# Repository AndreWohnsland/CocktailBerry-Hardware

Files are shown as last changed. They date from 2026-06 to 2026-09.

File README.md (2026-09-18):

CocktailBerry Hardware

<br/>



CocktailBerry Hardware is the **official hardware repository** for the [CocktailBerry](https://github.com/AndreWohnsland/CocktailBerry) project.
It holds the machine designs (FreeCAD sources) and custom PCB(A)s (KiCad projects) you need to build your own CocktailBerry machine.

<a href="https://cocktailberry.org/">website</a>
<a href="https://hardware.cocktailberry.org/">hardware documentation</a>
<a href="https://docs.cocktailberry.org/">software documentation</a>

Build guides, parts lists, specifications, and downloadable fabrication files live in the
**[Hardware Documentation](https://hardware.cocktailberry.org/)**. For the software, setup, and
configuration, see the [main CocktailBerry project](https://github.com/AndreWohnsland/CocktailBerry)
and the [Software Documentation](https://software.cocktailberry.org/).

Like this project? Give the main repo a star on GitHub! ⭐

# Designs

Sources live in this repo; fabrication files (Gerbers/BOM/CPL for boards, STEP/STL for machines)
are generated from them by the build pipeline. Full specs, parts, and downloads are on the
[Hardware Documentation](https://hardware.cocktailberry.org/).

**PCBAs** ([`pcb/`](pcb)) — control boards that replace relay arrays, switching pump circuits via MOSFETs:

| Board | Description | Status |
| --- | --- | --- |
| [CocktailBerryBoard GPIO](https://hardware.cocktailberry.org/pcbas/cocktailberry-board-gpio/) | GPIO-based, up to 10 circuits | Released |
| [CocktailBerryBoard Slim](https://hardware.cocktailberry.org/pcbas/cocktailberry-board-slim/) | Compact GPIO-based, up to 8 circuits | Released |
| [CocktailBerryBoard I2C](https://hardware.cocktailberry.org/pcbas/cocktailberry-board-i2c/) | I2C-based, up to 10 circuits | Beta |

**Machines** ([`cad/`](cad)) — 3D-printable machine builds:

| Machine | Description | Status |
| --- | --- | --- |
| [CocktailBerry MK III](https://hardware.cocktailberry.org/machines/mk3/) | Compact footprint with integrated touchscreen support  | Released |
| [CocktailBerry 2-Go](https://hardware.cocktailberry.org/machines/2-go/)  | Portable Euro Box build with detachable legs | Released |
| [CocktailBerry MK IV](https://hardware.cocktailberry.org/machines/mk4/)  | v2 reference build, optional scale + peristaltic pumps | Beta |

# Contributing / How to Help

Contributions are very welcome - a new machine design, an improved model, or a PCB layout.
Open an issue or pull request.

**Please submit source files only:**

- PCBs: the KiCad project (`*.kicad_sch`, `*.kicad_pcb`, and any local symbols/footprints)
- Machines: the FreeCAD sources (`*.FCStd`)

Do **not** commit generated fabrication artifacts (Gerbers, drill, CPL, STL, STEP) - those are
built from the sources by the pipeline (see [`pcb/README.md`](pcb/README.md) and
[`cad/README.md`](cad/README.md)). See the main project's
[Contributing Guidelines](https://github.com/AndreWohnsland/CocktailBerry/blob/master/CONTRIBUTING.md)
for general rules.

# Related Projects

| Project | Description |
| --- | --- |
| [CocktailBerry](https://github.com/AndreWohnsland/CocktailBerry) | The main software project (Python + React) |
| [CocktailBerry Addons](https://github.com/AndreWohnsland/CocktailBerry-Addons) | Community addons and extensions |
| [Software Documentation](https://software.cocktailberry.org/) | Software setup and configuration guides |

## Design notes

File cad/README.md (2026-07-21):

# CAD sources

FreeCAD sources for the machines. Manufacturing artifacts (STEP + STL) are
generated headlessly - on release by CI, or locally - via
[`scripts/export_freecad.py`](../scripts/export_freecad.py) (runs under FreeCAD's
`freecadcmd`) and [`scripts/build_artifacts.py`](../scripts/build_artifacts.py)
(the uv-driven orchestrator that zips per machine).

## Layout & conventions

```shell
cad/machines/<machine>/
  *.FCStd        # exported  (files in the folder ROOT)
  lib/           # helpers / imported sources - NOT exported (any subfolder)
  export.toml    # optional: pin which objects to export per file
cad/accessories/ # shared extra hardware - same conventions, own export unit
```

- **File selection:** every `*.FCStd` in a machine-folder **root** is exported.
  Put helper or imported documents in a **subfolder** (e.g. `lib/`) to skip them.
- **Prebuilt files:** `*.3mf` in a folder root are copied into the zip as-is
  (no CAD source needed; pattern list in `build_artifacts.py`).
- **Object selection** per file:
  - One result body in the file → exported automatically, no config needed.
  - Multiple candidates (e.g. a base that forks into variants) → the run fails
    and lists them, so you pin the ones you want in `export.toml`, keyed by the
    file name without `.FCStd`:
    ```toml
    [main_body]
    objects = ["MainBodyStandard", "MainBodyTall", "MainBodyCompact"]
    ```
  - Output files are named after each object's **Label** - name objects
    meaningfully.

## Running

FreeCAD is **not** a uv dependency; install it separately (`apt-get install
freecad` on CI). Then:

```bash
uv run python scripts/build_artifacts.py                # all units -> dist/<unit>.zip
uv run python scripts/build_artifacts.py mk3 accessories # selected units
```

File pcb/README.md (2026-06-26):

# PCB

KiCad projects for the CocktailBerry boards (and room for other PCB-related
components later). JLCPCB fabrication files (Gerbers, drill, BOM, CPL) are
generated headlessly - on release by CI, or locally - with
[KiKit](https://github.com/yaqwsx/KiKit) via
[`scripts/build_fab.py`](../scripts/build_fab.py).

## Layout & conventions

```shell
pcb/<board>/
  <board>.kicad_pcb   # exactly one PCB per board folder
  <board>.kicad_sch   # root schematic (shares the project base name)
  *.kicad_sch         # hierarchical sub-sheets (e.g. a reused pump circuit)
  ...                 # symbols/footprints/etc. live alongside as usual
```

- Each board folder must contain **exactly one** `*.kicad_pcb` (one layout per
  project, no matter how many schematic sheets exist).
- **Hierarchical schematics are fine.** Only the **root** sheet (named after the
  project, like the `.kicad_pcb`) is passed to KiKit; it walks the hierarchy and
  pulls in all sub-sheets - so a pump circuit reused 10× flattens into the
  BOM/CPL automatically.
- Components to be assembled need their **LCSC part number** in the `MPN`
  schematic field (see `LCSC_FIELD` in `scripts/build_fab.py`). Parts without it
  appear in the BOM without an LCSC code and won't be placed.

## Running

KiKit + KiCad (`pcbnew`) are **not** uv dependencies; install them separately
(`apt-get install kicad` + `pip install kikit` on CI). Then:

```bash
uv run python scripts/build_fab.py            # all boards -> dist/<board>.zip
uv run python scripts/build_fab.py cbb-gpio    # a single board
```

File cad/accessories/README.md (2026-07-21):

# Accessories

FreeCAD sources for additional hardware that is not tied to one specific
machine. Same layout and export conventions as a machine folder - see
[`cad/README.md`](../README.md).

Empty for now; parts land here over time. The build packages this folder as
its own unit to `dist/accessories.zip` (skipped while there is nothing to
export).

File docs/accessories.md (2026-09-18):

---
tags: [Accessory]
icon: material/puzzle-outline
---

# Accessories

Additional hardware to extend a CocktailBerry machine - add-ons that are not tied to one specific machine build.

## Setup

Setup instructions for each accessory will be added here as they are released.

## Downloads

The printable and CAD files are attached to each [release]({{extra.repo_url}}/releases) as a single archive, starting with v1.1:

- **3D files:**
  [`accessories.zip`]({{extra.repo_url}}/releases/latest/download/accessories.zip)
  - STL (print-ready) and STEP (CAD) for every part.

## CocktailBerry Site Plate

If you want to spread the word about CocktailBerry, you can print a small plate with the QR code to the official site.
It also includes a small storage box, printed in vase/spiral mode to hold the cards.
Print it twice, the second one just roughly 3-4% larger so you can fit them together.
The cards are just stored within the box, and can be printed on a standard printer.
Use a color change at a certain height to print the QR code in a different color, or just paint it afterwards.

You will need the PlateBox as well as the CocktailBerryPagePlates files.

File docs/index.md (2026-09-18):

---
icon: material/home-outline
---

# CocktailBerry Hardware

Welcome to the official **hardware** documentation for [CocktailBerry](https://cocktailberry.org) - the open-source software to easily build your own automated cocktail machine.

While the [main documentation](https://software.cocktailberry.org) covers the software, this site collects everything you need to **build the physical machine**:
printed circuit board assemblies and 3D-printable machine designs, including the parts needed for each build.

Related project sites:

<div class="mid-flex">
<a href="https://demo.cocktailberry.org/" class="cta-btn primary-btn"> Software Demo </a>
  <a href="https://cocktailberry.org/" class="cta-btn secondary-btn"> Homepage </a>
  <a href="https://software.cocktailberry.org/" class="cta-btn primary-btn"> Software Docs </a>
</div>

## Sections

<div class="grid cards" markdown>

- :material-chip: **[PCBAs](pcbas/index.md)**

    Printed circuit boards to power your custom machine, ready to use.

- :material-printer-3d: **[Machines](machines/index.md)**

    3D models (STLs), part list, preparation, and assembly guides.

- :material-puzzle: **[Accessories](accessories.md)**

    Additional hardware to extend your machine.

</div>

!!! heart "Support CocktailBerry"

    CocktailBerry is free and open source.
    Developing the hardware, though, takes real time and money:
    every design goes through many iterations, and parts that don't fit end up in the bin.

    If this project brought you joy or saved you effort, [see how you can support CocktailBerry](https://software.cocktailberry.org/support/)
    - there are many ways to help, and most cost nothing but a little time.

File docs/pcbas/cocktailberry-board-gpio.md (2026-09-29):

---
tags: [PCBA]
---

# CocktailBerryBoard GPIO

The **CocktailBerryBoard** is a dedicated control board for CocktailBerry machines.
It replaces the extensive wiring and generic relay arrays normally used to switch the pumps, giving you clean, repeatable wiring on a single board.
It drives its outputs directly from the Raspberry Pi's GPIO pins.

--8<-- "board/released.md"

<figure markdown>
  Top view
  <figcaption>Top view of the board</figcaption>
</figure>

## Overview

The board switches up to **10 circuits** through the Raspberry Pi's GPIO pins and on-board **MOSFETs**, replacing relay arrays with a quieter and more compact solution.
Each output carries a built-in **flyback (freewheeling) diode**, and the 12 V supply can be **daisy-chained** onward, which keeps wiring across the machine simple.

Although it was designed for the [MK III](../machines/mk3/index.md), it works with any device that can be controlled from a GPIO output.

## Specifications

| Property | Detail |
| --- | --- |
| Variant | GPIO (CBB-GPIO) |
| Channels | Up to 10 independently switched circuits |
| Switching | MOSFET, driven from Raspberry Pi GPIO |
| Wiring | One signal header pin per channel + 2×GND |
| Power | 12 V input **and** output connector (PSU daisy-chain) |
| Dispenser outputs | One (+/–) connector per dispenser - no voltage conversion |
| Protection | Input fuse and per-channel flyback diodes |
| Indication | On/off status LED |

## Mechanical

- Shares the **Raspberry Pi mounting-hole pattern**, so the board and a Pi can be
  stacked / co-mounted.
- It is **not** a HAT - it does not plug onto the Pi's 40-pin header. Connections are
  made via **pin headers**: one signal pin per channel, plus 2 × GND, wired to the
  Pi's GPIO.

## Files

Production files are attached to each [release][releases] as a single archive, generated with KiKit:

- **Fabrication package (JLCPCB):**
  [`cbb-gpio.zip`]({{extra.repo_url}}/releases/latest/download/cbb-gpio.zip)
  - Gerbers, BOM, and positions (pick-and-place).

All parts (SMD, THT) are included in the package, so you can order the board and all parts from JLCPCB directly.

[releases]: {{extra.repo_url}}/releases

--8<-- "board/ordering.md"

--8<-- "disclaimer.md"

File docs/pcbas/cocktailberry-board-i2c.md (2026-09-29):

---
tags: [PCBA]
---

# CocktailBerryBoard I2C

The **CocktailBerryBoard** is a dedicated control board for CocktailBerry machines.
It replaces the extensive wiring and generic relay arrays normally used to switch the pumps, giving you clean, repeatable wiring on a single board.
It drives its outputs directly from the Raspberry Pi's I²C interface.

--8<-- "board/beta.md"

<figure markdown>
  Top view
  <figcaption>Top view of the board</figcaption>
</figure>

## Overview

The board switches up to **10 circuits** through the Raspberry Pi's I²C interface and on-board **MOSFETs**, replacing relay arrays with a quieter and more compact solution.
Each output carries a built-in **flyback (freewheeling) diode**, and the 12 V supply can be **daisy-chained** onward, which keeps wiring across the machine simple.
The I²C bus can be daisy-chained to further devices, sharing the Pi's single bus.

Although it was designed for the [MK IV](../machines/mk4/index.md), it works with any device that can be controlled over I²C.

## Specifications

| Property | Detail |
| --- | --- |
| Variant | I²C (CBB-I2C) |
| Channels | Up to 10 independently switched circuits |
| Switching | MOSFET, driven from Raspberry Pi I²C |
| Wiring | 2×4 Pin Headers, 2×SH 4 pin (SDA, SCL, GND, VCC) |
| Power | 12 V input **and** output connector (PSU daisy-chain) |
| Dispenser outputs | One (+/–) connector per dispenser - no voltage conversion |
| Protection | Input fuse and per-channel flyback diodes |
| Indication | On/off status LED |

## Mechanical

- Shares the **Raspberry Pi mounting-hole pattern**, so the board and a Pi can be
  stacked / co-mounted.
- It is **not** a HAT - it does not plug onto the Pi's 40-pin header. Connections are
  made via **pin headers**: one 4-pin header per channel, wired to the
  Pi's I²C interface.

## Extender Mapping

Currently, the default I²C address is `0x27`, and the board can be configured to use addresses down to `0x20` by soldering the appropriate jumpers (A0, A1, A2) on the board.
The channels are mapped to the pumps as follows: *0 to 1, 1 to 2, ..., 9 to 10* (Pump - 1 = Pin/Channel).
Use this number for the CocktailBerry software as the pin number of the pump.

## Files

Production files are attached to each [release][releases] as a single archive, generated with KiKit:

- **Fabrication package (JLCPCB):**
  [`cbb-i2c.zip`]({{extra.repo_url}}/releases/latest/download/cbb-i2c.zip)
  - Gerbers, BOM, and positions (pick-and-place).

All parts (SMD, THT) are included in the package, so you can order the board and all parts from JLCPCB directly.

[releases]: {{extra.repo_url}}/releases

--8<-- "board/ordering.md"

--8<-- "disclaimer.md"

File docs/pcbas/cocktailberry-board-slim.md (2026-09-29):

---
tags: [PCBA]
---

# CocktailBerryBoard Slim

The **CocktailBerryBoard** is a dedicated control board for CocktailBerry machines.
It replaces the loose jumper wires and generic relay arrays normally used to switch the pumps, giving you clean, repeatable wiring on a single board.
It drives its outputs directly from the Raspberry Pi's GPIO pins.
This is a variant of the GPIO-based board (CBB-GPIO), with a smaller form factor and fewer channels, designed for compact builds.

--8<-- "board/released.md"

<figure markdown>
  Top view
  <figcaption>Top view of the board</figcaption>
</figure>

## Overview

The board switches up to **8 circuits** through the Raspberry Pi's GPIO pins and on-board **MOSFETs**, replacing relay arrays with a quieter and more compact solution.
Each output carries a built-in **flyback (freewheeling) diode**, and the 12 V supply can be **daisy-chained** onward, which keeps wiring across the machine simple.

Although it was designed for the [2-Go](../machines/2-go/index.md), it works with any device that can be controlled from a GPIO output.

## Specifications

| Property | Detail |
| --- | --- |
| Variant | GPIO (CBB-Slim) |
| Channels | Up to 8 independently switched circuits |
| Switching | MOSFET, driven from Raspberry Pi GPIO |
| Wiring | One signal header pin per channel + 2×GND |
| Power | 12 V input **and** output connector (PSU daisy-chain) |
| Dispenser outputs | One (+/–) connector per dispenser - no voltage conversion |
| Protection | Input fuse and per-channel flyback diodes |
| Indication | On/off status LED |

## Mechanical

- It is **not** a HAT - it does not plug onto the Pi's 40-pin header. Connections are
  made via **pin headers**: one signal pin per channel, plus 2 × GND, wired to the
  Pi's GPIO.
- Narrower than the CBB-GPIO, but with a longer body.

## Files

Production files are attached to each [release][releases] as a single archive, generated with KiKit:

- **Fabrication package (JLCPCB):**
  [`cbb-slim.zip`]({{extra.repo_url}}/releases/latest/download/cbb-slim.zip)
  - Gerbers, BOM, and positions (pick-and-place).

All parts (SMD, THT) are included in the package, so you can order the board and all parts from JLCPCB directly.

[releases]: {{extra.repo_url}}/releases

--8<-- "board/ordering.md"

--8<-- "disclaimer.md"

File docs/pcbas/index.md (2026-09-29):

---
tags: [PCBA]
icon: material/memory
---

# PCBAs

Printed circuit board assemblies for CocktailBerry.
Each PCBA has its own page with its capabilities, specifications, and (where available) design and production files.

## Available PCBAs

- [CocktailBerryBoard GPIO](cocktailberry-board-gpio.md): GPIO-based control board that replaces relay arrays, switching up to 10 circuits via MOSFETs.
- [CocktailBerryBoard I2C](cocktailberry-board-i2c.md): I2C-based control board that replaces relay arrays, switching up to 10 circuits via MOSFETs.
- [CocktailBerryBoard Slim](cocktailberry-board-slim.md): Compact GPIO-based control board that replaces relay arrays, switching up to 8 circuits via MOSFETs.

## Ordering

Boards can be ordered fully assembled - the [ordering guide](ordering.md) walks through a JLCPCB order step by step.

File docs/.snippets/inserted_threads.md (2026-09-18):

## Threaded Inserts

You will need threaded inserts in a variety of sizes, mostly M2.5, 3, 4, 5, maybe 6 (short versions also work). Make sure your inserts fit the following hole diameters.
I used [CNC Kitchen inserts](https://cnckitchen.store/collections/threaded-inserts) and their dimensions for the machine.

| Insert Size | Material Hole Diameter (mm) |
| --- | --- |
| M2.5 | 4.0 |
| M3 | 4.0 |
| M4 | 5.7 |
| M5 | 6.5 |
| M6 | 8.1 |

Please note that most Amazon products have a smaller diameter; especially many of the M2.5 will "fall through" the hole.
I recommend either checking your dimensions, or going with CNC Kitchen products, which are designed for 3D-printed parts and have the correct dimensions.
These [threaded inserts](https://amzn.to/4xFULJX) come close to the CNC ones.
When using something [like those](https://amzn.to/4oJ0DOu), you will probably need smaller holes.
If your inserts require different hole sizes, you will need to adjust the STL files accordingly.
The hole diameters are defined in the parameter file.

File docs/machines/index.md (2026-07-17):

---
tags: [Machine]
icon: material/glass-cocktail
---

# Machines

Everything needed to build a CocktailBerry machine: 3D-printable parts (STLs), preparation steps, and assembly guides.
Each machine has its own section, including the parts needed for that build.

## Available Machines

- [CocktailBerry MK III](mk3/index.md): 3D-printed with a compact footprint and integrated touchscreen support.
- [CocktailBerry MK IV](mk4/index.md): The latest v2-focused reference build with a cleaner design and optional scale plus peristaltic pump support.
- [CocktailBerry 2-Go](2-go/index.md): A compact portable build in a Euro Box with detachable legs optimized for transport.

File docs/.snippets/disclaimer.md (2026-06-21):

!!! warning "Disclaimer"

    The CocktailBerry hardware is **open-source** and provided **as-is**, without any
    warranty. You build, modify, and operate it **at your own risk**. Always follow
    local electrical-safety regulations and double-check wiring, polarity, and supply
    voltages before powering a board. Neither the authors nor the contributors are
    liable for any damage, injury, or loss resulting from its use.

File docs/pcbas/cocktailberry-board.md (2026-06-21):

# CocktailBerryBoard

The **CocktailBerryBoard** is a dedicated control board for CocktailBerry machines.
It replaces the loose jumper wires and generic relay arrays normally used to switch
the pumps, giving you clean, repeatable wiring on a single board.

It is currently available as a **GPIO-based** board (CBB-GPIO), driving its outputs
directly from the Raspberry Pi's GPIO pins. An I²C-based variant may follow in the
future.

--8<-- "board/released.md"

## Overview

The board switches up to **10 circuits** through the Raspberry Pi's GPIO pins and
on-board **MOSFETs**, replacing relay arrays with a quieter, more compact, and more
reliable solution. Each output carries a built-in **flyback (backflow) diode**, and
the 12 V supply can be **daisy-chained** onward, which keeps wiring across the
machine simple.

Although it was designed for the [MK III](../machines/mk-iii/index.md), it works with
any device that can be controlled from a GPIO output.

## Specifications

| Property | Detail |
| --- | --- |
| Variant | GPIO (CBB-GPIO) |
| Channels | Up to 10 independently switched circuits |
| Switching | MOSFET, driven from Raspberry Pi GPIO |
| Per-channel diode | Built-in flyback / backflow protection |
| Wiring | One signal header pin per channel + 2 × GND |
| Power | 12 V input **and** output connector (PSU daisy-chain) |
| Dispenser outputs | One (+/–) connector per dispenser — no voltage conversion |
| Protection | Input fuse and per-channel flyback diodes |
| Indication | On/off status LED |
| Status | Released — production-ready (JLCPCB artifacts) |

## Mechanical

- Shares the **Raspberry Pi mounting-hole pattern**, so the board and a Pi can be
  stacked / co-mounted.
- It is **not** a HAT — it does not plug onto the Pi's 40-pin header. Connections are
  made via **pin headers**: one signal pin per channel, plus 2 × GND, wired to the
  Pi's GPIO.

## Files

Production files are attached to each [release][releases] as a single archive,
generated with KiKit:

- **Fabrication package (JLCPCB):**
  [`cbb-gpio.zip`]({{extra.repo_url}}/releases/latest/download/cbb-gpio.zip)
  — Gerbers, drill, BOM, and CPL (pick-and-place).

!!! info
    The link always points to the **latest release** and will 404 until the
    first release is published.

[releases]: {{extra.repo_url}}/releases

--8<-- "disclaimer.md"

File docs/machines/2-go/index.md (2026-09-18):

---
tags: [Machine]
---

# CocktailBerry 2-Go

The **CocktailBerry 2-Go** is a portable, compact CocktailBerry machine.
It might not be the prettiest, but it is designed to be easily built and used on the go.
It uses a Euro Box enclosure and 3D-printed parts to hold everything together, and it can be powered by a 12 V battery pack for true portability.
You can also use a normal 12 V power supply if you don't need to take it on the road.
The legs can be detached for easier transport, and the whole thing can be stored in a backpack or small case.

--8<-- "machine/released.md"

<figure markdown>
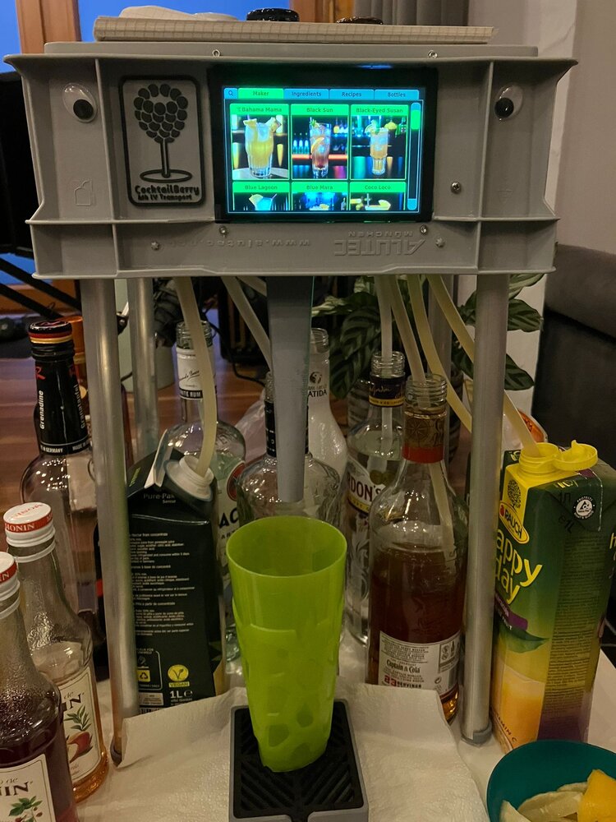
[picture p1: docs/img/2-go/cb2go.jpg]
CocktailBerry 2-Go
  
  <figcaption>Front view of the machine with touchscreen</figcaption>
</figure>

## Specifications

| Property | Value |
| --- | --- |
| Dispensers | 8 × membrane pumps |
| Display | 5" integrated LCD touchscreen or smartphone |
| Controller | Raspberry Pi 3 Model B+ (newer models also work) |
| Power | 12 V input; internal DC-DC converter powers the Pi |
| Software | CocktailBerry v1 or v2 (no touchscreen) |
| Enclosure  | Euro Box, 3D-printed parts inside |
| Dimensions | 30×20×12 cm (box), ~50 cm high with legs |

## Downloads

The printable and CAD files are attached to each [release]({{extra.repo_url}}/releases) as a single
archive:

- **3D files:**
  [`2go.zip`]({{extra.repo_url}}/releases/latest/download/2go.zip)
  - STL (print-ready) and STEP (CAD) for every part.

## Build Guide

1. [Needed Parts](needed-parts.md) - what to print, buy, and have ready.
2. [Preparation](preparation.md) - printing, post-processing, and prep work.
3. [Assembly](assembly.md) - putting it all together.

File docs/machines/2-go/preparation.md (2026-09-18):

---
tags: [Machine]
---

# Preparation

Steps to complete before assembly.

--8<-- "machine/preparation.md"

## Step A - Heat-Set Inserts

First, heat-set the threaded inserts (using a soldering iron) into the printed parts that require them.
Here is an overview of which insert goes where:

- Funnel: one M2.5 on the top connecting point
- Pump Grid: eight M2.5 on the pump mounting points, two M3 on the sides of the top, two M4 on the extensions coming from the grid
- Main Board: one M3 on the fillet facing front, eight M2.5 on the electric mounting points
- Leg Holder: two M4 in the plain face facing outside, four M2.5 on the electric mounting points facing inside in ONE of both leg holders

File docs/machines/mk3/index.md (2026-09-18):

---
tags: [Machine]
---

# CocktailBerry MK III

The **MK III** is the successor to the MK II and the reference build for the CocktailBerry **v1** software; the [MK IV](../mk4/index.md) is the reference build for **v2**.
By moving the wiring onto the [CocktailBerryBoard](../../pcbas/cocktailberry-board-gpio.md), it achieves a noticeably smaller footprint while keeping the full feature set of its predecessor.

It is fully 3D-printed and designed to be produced on a common **250 × 250 mm** print bed.

--8<-- "machine/released.md"

<figure markdown>
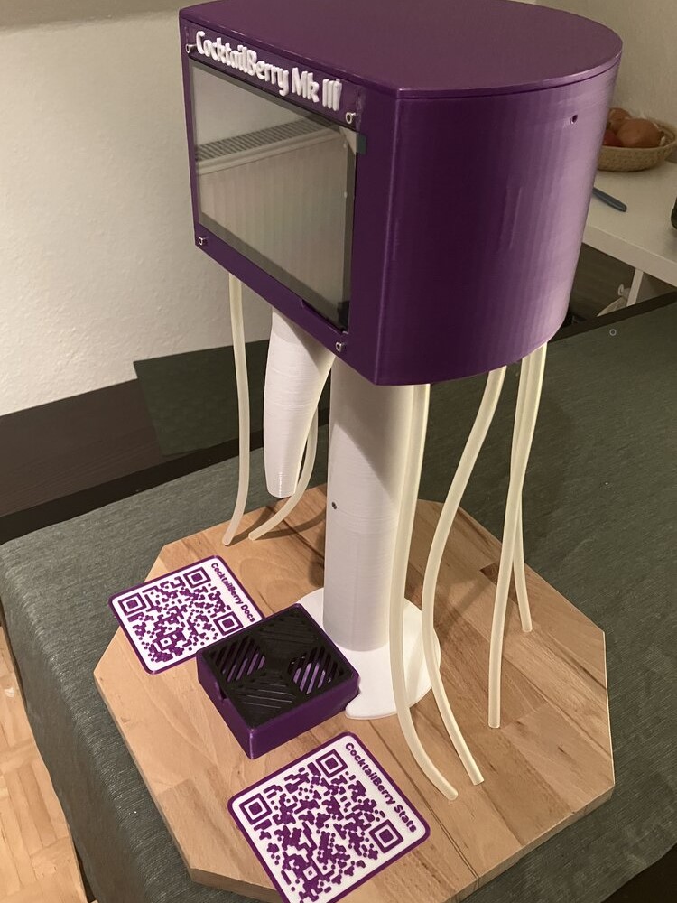
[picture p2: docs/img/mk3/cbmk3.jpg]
CocktailBerry MK III
  
  <figcaption>Side view of the machine</figcaption>
</figure>

## Specifications

| Property | Value |
| --- | --- |
| Dispensers | 8 × membrane pumps |
| Display | 7" integrated LCD touchscreen |
| Controller | Raspberry Pi 3 Model B+ (newer models also work) |
| Power | 12 V input; internal DC-DC converter powers the Pi |
| Software | CocktailBerry v1 (Qt); also runs v2 |
| Enclosure  | Fully 3D-printed (fits a 250 × 250 bed) |
| Dimensions | ⌀ ~240 mm × ~550 mm (H) |

Because the touchscreen is built in, the **v1** app is the natural fit, but the machine can also be run with **v2**.

!!! note "Base build"
    The MK III documented here is the base machine. Optional CocktailBerry
    capabilities - WS281x LEDs, RFID/NFC payment, scale/weight sensing, and
    carriages - are **not** part of this build.

## Downloads

The printable and CAD files are attached to each [release]({{extra.repo_url}}/releases) as a single archive:

- **3D files:**
  [`mk3.zip`]({{extra.repo_url}}/releases/latest/download/mk3.zip)
  - STL (print-ready) and STEP (CAD) for every part.

## Build Guide

1. [Needed Parts](needed-parts.md) - what to print, buy, and have ready.
2. [Preparation](preparation.md) - printing, post-processing, and prep work.
3. [Assembly](assembly.md) - putting it all together.

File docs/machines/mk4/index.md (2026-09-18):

---
tags: [Machine]
---

# CocktailBerry MK IV

The **MK IV** is the reference build for the CocktailBerry **v2** software (the [MK III](../mk3/index.md) remains the reference for **v1**).
Like the MK III, it moves the wiring onto the [CocktailBerryBoard](../../pcbas/cocktailberry-board-gpio.md).
It is more streamlined and visually appealing, and adds the option to use a scale.
The base build also includes two peristaltic pumps, allowing the use of syrup in the machine.

It is fully 3D-printed and designed to be produced on a common **250 × 250 mm** print bed.

--8<-- "machine/beta.md"

<figure markdown>
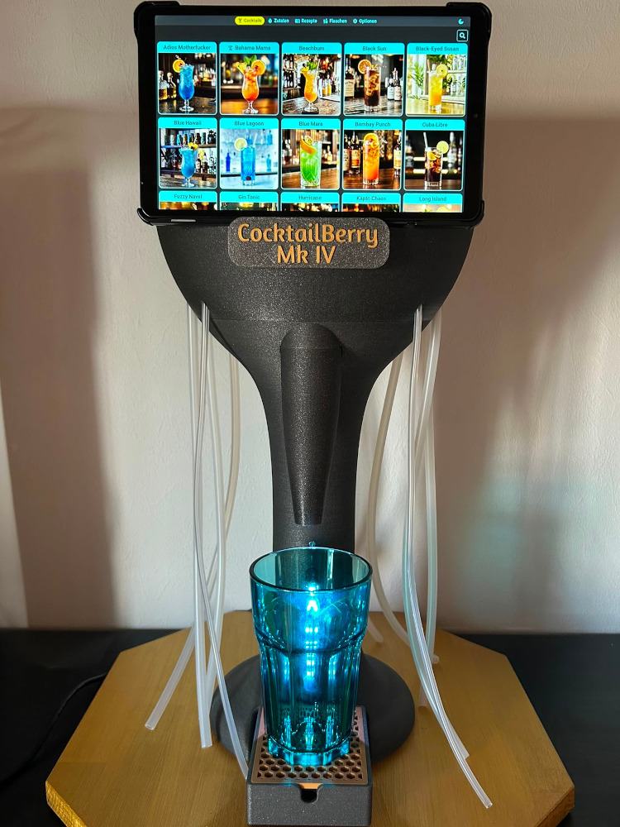
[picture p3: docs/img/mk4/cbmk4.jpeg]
CocktailBerry MK IV
  
  <figcaption>Side view of the machine</figcaption>
</figure>

## Specifications

| Property | Value |
| --- | --- |
| Dispensers | 8 × membrane pumps + 2 × peristaltic pumps |
| Display | Tablet or Smartphone |
| Controller | Raspberry Pi 4 or 5 |
| Power | 12 V input; internal DC-DC converter powers the Pi |
| Software | CocktailBerry v2 |
| Enclosure  | Fully 3D-printed |
| Dimensions | ⌀ ~240 mm × ~500 mm (H) |
| Scale | Optional, below the Draining Rack |
| LEDs | Optional, behind the glass |

## Downloads

The printable and CAD files are attached to each [release]({{extra.repo_url}}/releases) as a single archive:

- **3D files:**
  [`mk4.zip`]({{extra.repo_url}}/releases/latest/download/mk4.zip)
  - STL (print-ready) and STEP (CAD) for every part.

## Build Guide

1. [Needed Parts](needed-parts.md) - what to print, buy, and have ready.
2. [Preparation](preparation.md) - printing, post-processing, and prep work.
3. [Assembly](assembly.md) - putting it all together.

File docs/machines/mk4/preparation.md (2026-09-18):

---
tags: [Machine]
---

# Preparation

Steps to complete before assembly.

--8<-- "machine/preparation.md"

<figure markdown>
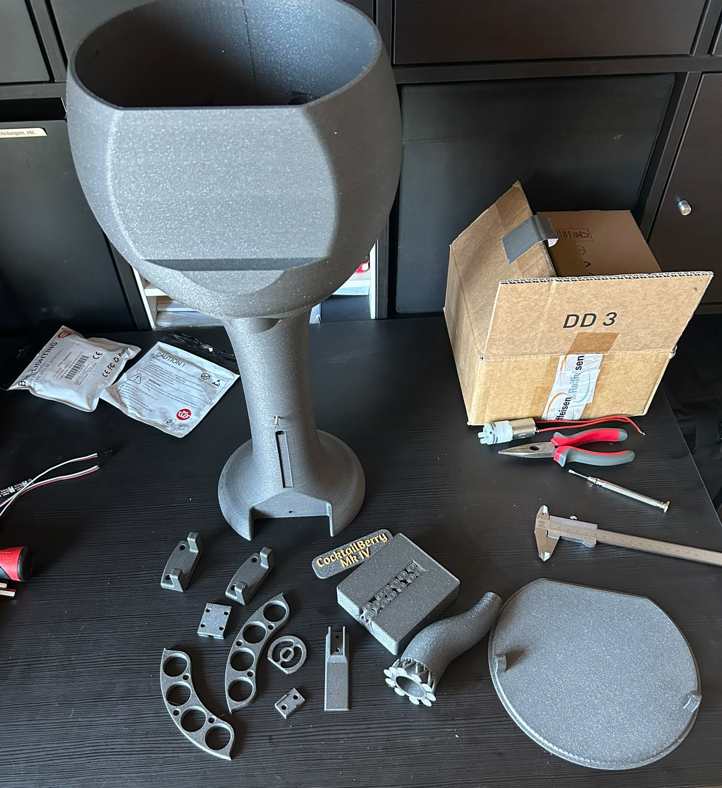
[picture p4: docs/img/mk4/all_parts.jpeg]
  
  <figcaption>All parts of the CocktailBerry MK IV</figcaption>
</figure>

## Step A - Heat-Set Inserts

First, heat-set the threaded inserts (using a soldering iron) into the printed parts that require them.
Here is an overview of which insert goes where:

- Lid Top: two M3 on the pads
- Tower Bottom: two M3 on the top connecting point, two M5 on the bottom
- Tower Middle: three M4 on the top connecting point
- Tower Top: eight M2.5 on the electric mounting points, three M3 each side on the pump sockets, two M3 each side on the peristaltic holders (front)
- Peristaltic holder: two M2.5 on the mounting points in the U-shape for each part
- Optional Scale: four M2.5 into the scale electrics socket

<figure markdown>
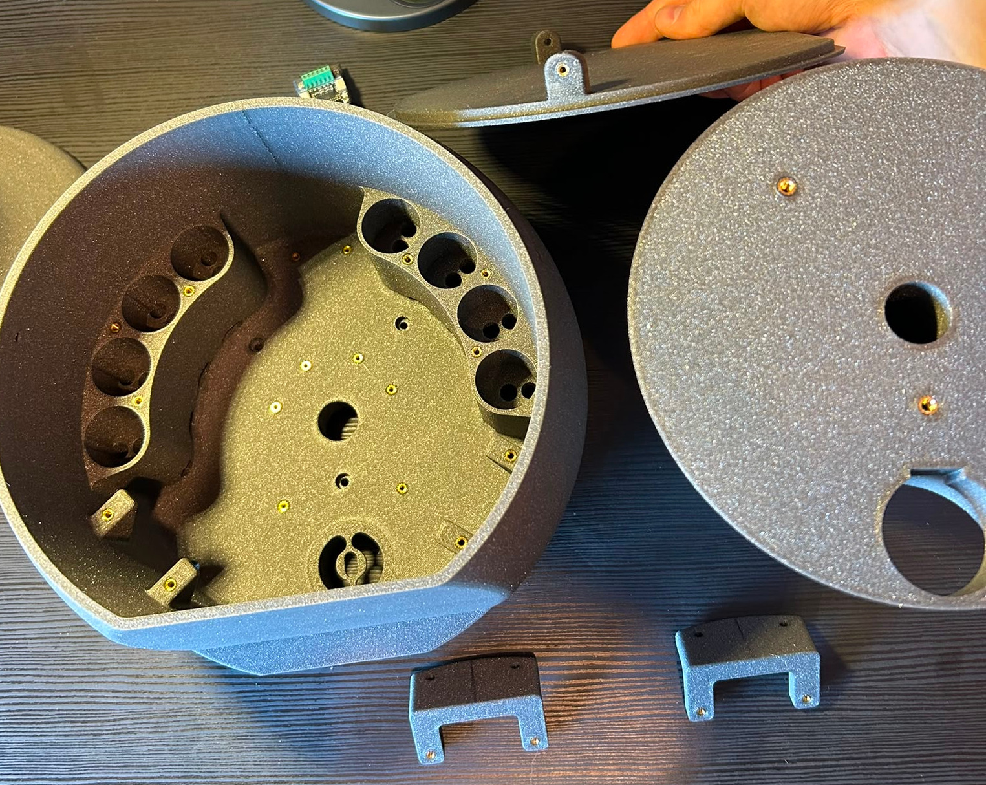
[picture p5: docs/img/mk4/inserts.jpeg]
  
  <figcaption>All parts of the CocktailBerry MK IV with inserts installed</figcaption>
</figure>

## Step B - Insert Magnets

Put the magnets into the slots of the funnel and the bundler, so they can hold together.

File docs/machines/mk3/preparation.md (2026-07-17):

---
tags: [Machine]
---

# Preparation

Steps to complete before assembly.

--8<-- "machine/preparation.md"

## Step A - Heat-Set Inserts

First, heat-set the threaded inserts (using a soldering iron) into the printed parts that require them.
Here is an overview of which insert goes where:

- Lid Tower: two M3 on the pads
- Tower Bottom: two M3 on the top connecting point, one M5 on the bottom
- Tower Middle (or ring LED): three M4 on the top connecting point
- Tower Top: eight M2.5 on the electric mounting points

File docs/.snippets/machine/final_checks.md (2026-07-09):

## Final Checks

- All connections secure
- Pumps run in the correct direction
- First test run with water completed

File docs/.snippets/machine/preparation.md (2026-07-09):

## Printing the Parts

These settings might differ a little bit, depending on your printer.
The parts are designed to be printed without supports, but some printers might require them for certain parts.

- Recommended material: PLA, PETG, or ABS (funnel should be food-safe)
- Layer height: 0.2 mm
- Infill: 10-20 %
- Supports: where needed

## Post-Processing

Remove supports and clean up the parts as needed.
Prepare boards, electronics, and fasteners for assembly.
Pre-solder connections where possible to save time during assembly.

## Pre-Assembly Checks

- All parts printed and cleaned
- Electronics tested
- Fasteners and tools ready
- Measure converter output voltage to ensure it's set to 5 V before connecting to the Pi

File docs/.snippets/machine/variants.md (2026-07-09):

Parts might have different variants; you will find the default under *default*.
Variants have the corresponding information (scale, LED, funnel, ...) in the notes column.
Optional parts are marked as such; you can skip them if you do not need them.

Also, the naming hints at the purpose, e.g.:

- PartWithoutX and PartWithX
- Part and PartX

where X is the feature that is added or removed.

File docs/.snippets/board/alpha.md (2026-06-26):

!!! warning "Alpha"
    This board is in **alpha**. The design is still changing and is **not**
    production-ready - expect breaking revisions and hold off on ordering until it is released.

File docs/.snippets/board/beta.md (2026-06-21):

!!! info "Beta"
    This board is in **beta**. The design is functional and under final validation.
    Production artifacts may be available, but minor revisions are still possible before release.

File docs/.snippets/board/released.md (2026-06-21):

!!! success "Released"
    This board is **released**. Full production artifacts (ready to order at JLCPCB) are available.

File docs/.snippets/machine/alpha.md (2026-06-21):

!!! warning "Alpha"
    This machine is in **alpha**. Parts and assembly steps are still changing, so
    hold off on a full build until the design stabilizes.

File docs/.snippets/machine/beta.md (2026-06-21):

!!! info "Beta"
    This machine is in **beta**. The build is functional and under final validation;
    print files and assembly steps may still receive minor changes before release.

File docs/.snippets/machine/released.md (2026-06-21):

!!! success "Released"
    This machine is **released**. The full set of 3D-print files (STLs) and the assembly guide are available.

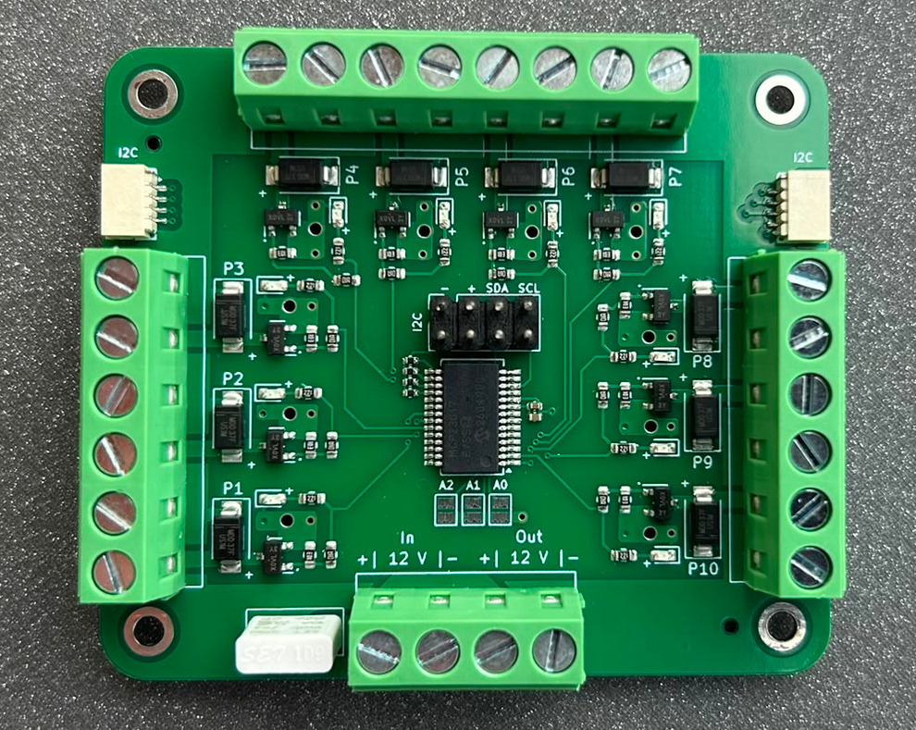
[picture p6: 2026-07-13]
docs/img/cbb-i2c/board_top.jpeg

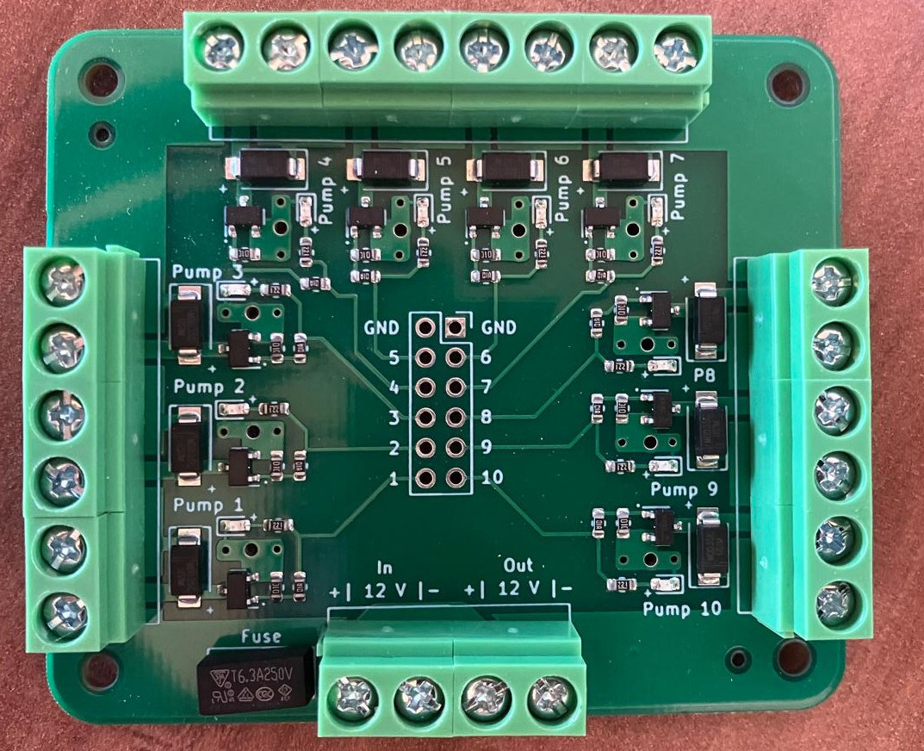
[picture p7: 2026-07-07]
docs/img/cbb-gpio/board_top.jpeg

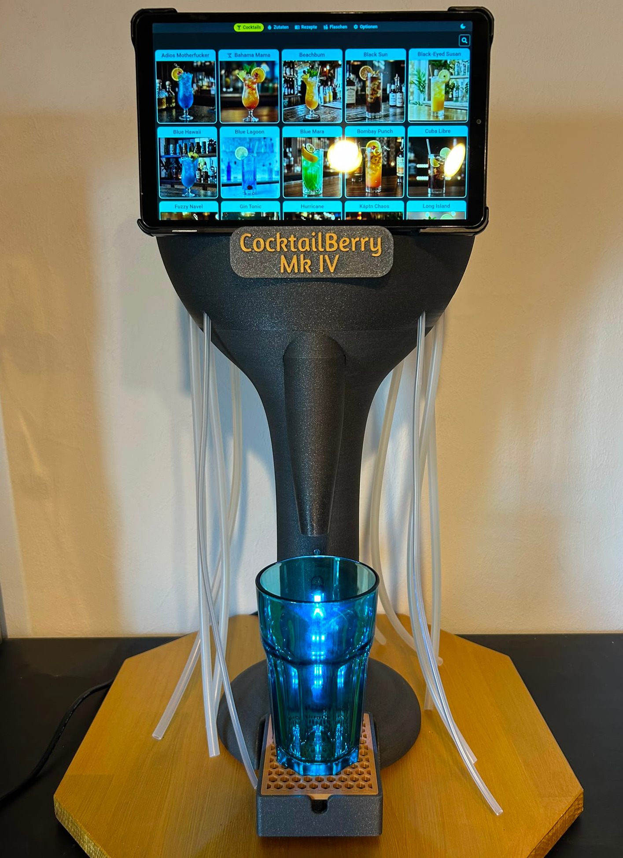
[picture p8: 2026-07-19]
docs/img/mk4/cbmk4_2.jpeg

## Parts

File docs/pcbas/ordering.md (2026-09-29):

---
tags: [PCBA]
icon: material/cart-outline
---

# Ordering at JLCPCB

Every CocktailBerryBoard ships as a ready-to-order fabrication package, so JLCPCB can manufacture **and** assemble the board for you - no soldering needed.
This page walks through one order, from upload to checkout.

## Before you start

Download the fabrication package for your board.
Every [PCBA page](index.md) links it under **Files**, and all packages are attached to each [release]({{extra.repo_url}}/releases).

Unpack it - the three files inside are everything the order needs:

| File | Purpose |
| --- | --- |
| `gerbers.zip` | The board itself (copper, mask, silkscreen, drill) |
| `bom.csv` | The parts, with their LCSC part numbers |
| `pos.csv` | Where each part goes (pick-and-place) |

## Board

1. Open the [JLCPCB quote page](https://jlcpcb.com/quote) and upload `gerbers.zip`.
2. Adjust the board options to taste - colour, lead-free and the like are yours to pick, the defaults work fine.
3. Switch **PCB Assembly** on and set **Tooling holes** to *Added by Customer*, then continue.
4. Check the rendered board preview, then continue.

## Parts

1. Upload `bom.csv` as the BOM and `pos.csv` as the pick-and-place file.
2. Process the BOM and walk through the matched parts. Most come back matched and preselected; where one does not, pick the proposed part and tick its checkbox.

!!! note "`H1`-`H4` are expected to be missing"

    The four mounting holes carry no part, so they are absent from the pick-and-place file and JLCPCB flags them. That warning is fine. Any **other** designator showing up there is not - stop and check your files.

<figure markdown>
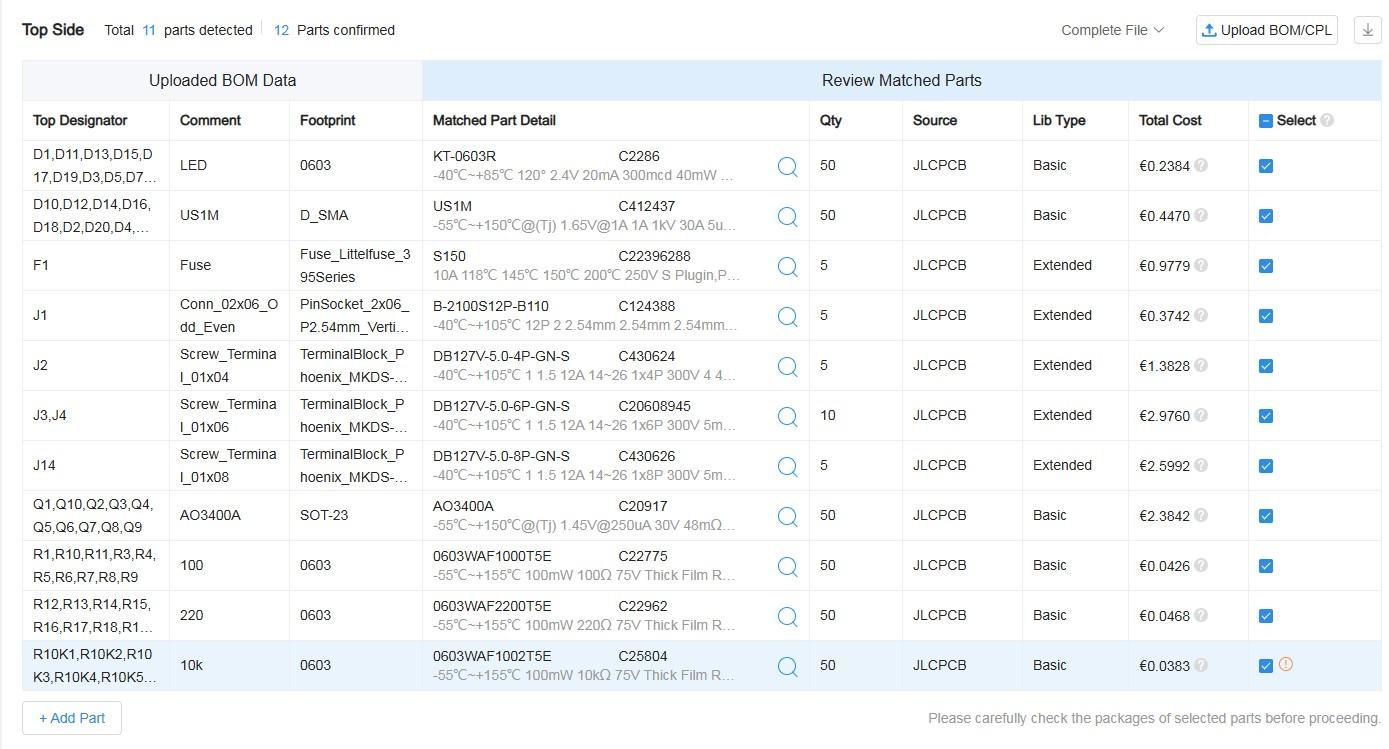
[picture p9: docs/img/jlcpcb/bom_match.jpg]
Reviewing the matched parts
  
  <figcaption>All parts matched and selected (example: CocktailBerryBoard GPIO)</figcaption>
</figure>

## Placement

Continue to the placement preview and check it: every part in its footprint, polarity markers where you expect them.

<figure markdown>
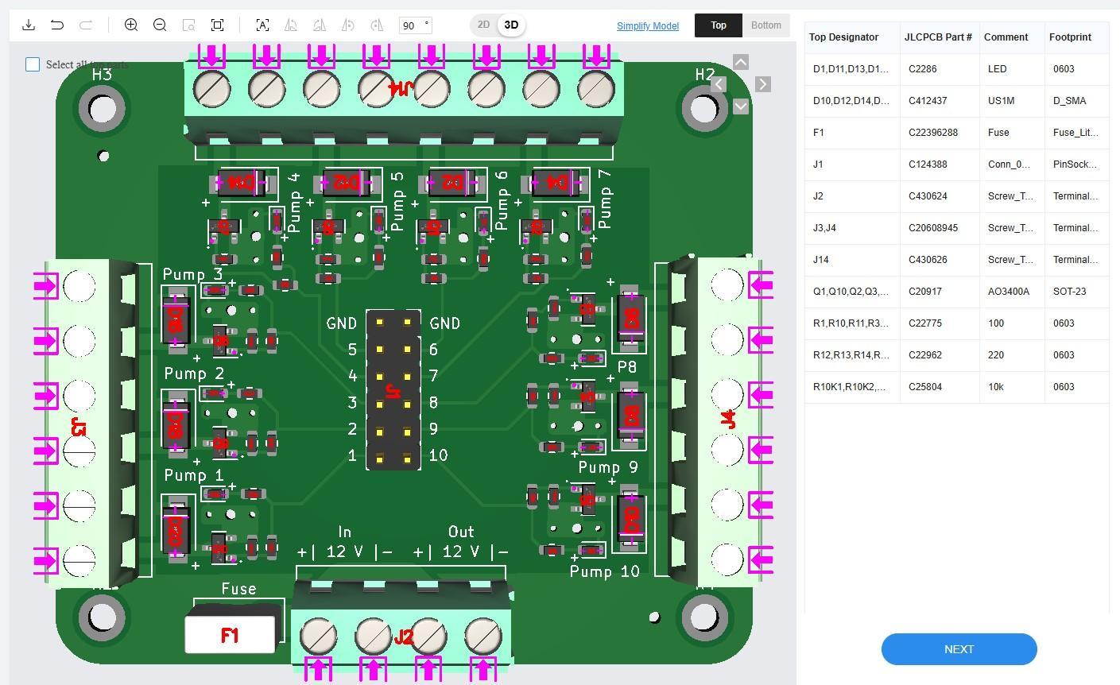
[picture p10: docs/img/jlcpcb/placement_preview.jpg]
Placement preview
  
  <figcaption>Correct part placement (example: CocktailBerryBoard GPIO)</figcaption>
</figure>

## Order

Continue to the quote, review it, and save the order to your cart.
Then check out - it pays to look for a coupon code before you do.

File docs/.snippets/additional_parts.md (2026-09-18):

## Additional Parts

In addition, you will need some "consumable" parts for a general build or other tools.
You might already have them lying around, but it's good to have them on the list for reference.

| Item | Qty |
| --- | --- |
| [Soldering Iron](https://amzn.to/4gvxtAb) | 1 |
| Soldering Wire | 1 Spool |
| Heat Shrink Tubing | 1 |
| [(Crimping) Pliers](https://amzn.to/44o02Iy) | 1 |
| Electric Wires | 5m |
| Wire End Ferrules | 30pc |
| Electric Screwdriver | 1 |
| Fitting Screws for Inserts | ~20pc |
| Glue for plastic | 1 |

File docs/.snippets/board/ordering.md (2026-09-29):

!!! tip "First time ordering a PCB?"

    The [step-by-step JLCPCB ordering guide](ordering.md) walks through a complete order, from uploading the package to checkout.

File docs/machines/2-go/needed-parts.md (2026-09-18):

---
tags: [Machine]
---

# Needed Parts

Everything required to build the CocktailBerry 2-Go.

## Printed Parts (STLs)

| Part | Qty | File | Notes |
| --- | --- | --- | --- |
| Pump Grid | 1 | PumpGrid | |
| Leg Holder | 2 | LegHolder | |
| Leg Stabilizers | 2 | LegStabilizers | |
| Main Board | 1 | MainBoard | |
| Electric Lid | 1 | ElectricLid | |
| Funnel | 1 | Funnel | |
| Foot Plugs | 4 | FootPlugs | *optional* |
| Foot Transport  | 2 | FootTransport  | *optional* |
| Machine Logo | 1 | MachineLogo | *optional* |

## Electronics

See also the [PCBAs](../../pcbas/index.md) section.

| Component | Qty | Notes |
| --- | --- | ----- |
| CBB-Slim  | 1 | |

## Hardware

| Item | Qty | Notes |
| --- | --- | --- |
| {{extra.pi_3bplus_link}} | 1 | {{extra.pi_5_link}} if no screen |
| {{extra.touch_5in_link}} | 1 | If you need screen (v1) |
| {{extra.sd_card_link}} | 1 | |
| {{extra.power_jack_2_5_mm_link}} | 1 | |
| {{extra.voltage_converter_link}} | 1 | |
| {{extra.power_supply_12v_link}} | 1 | |
| {{extra.membrane_pump_link}} | 8 | {{extra.membrane_pump_alt_link}} is also fine |
| {{extra.tubing_link}} | 5-10 m | 5×8 mm |
| {{extra.jumper_wires_link}} | 1 | 10 cm is long enough |
| {{extra.hex_standoffs_link}} | 16 | can use other height |
| {{extra.hdmi_cable_link}} | 1 | If you need screen (v1) |
| {{extra.usb_cable_link}} | 1 | If you need screen (v1) |
| {{extra.micro_usb_open_cable_link}} | 1 | For the RPi 3 |
| {{extra.usb_c_open_cable_link}} | 1 | For the RPi 4 or 5 |
| ⌀ 10 mm pipe, 55 cm | 4 | |

## Fasteners

For more information on the threaded inserts, see the section below.
The following inserts are required for the assembly of the machine:

| Metric | Qty |
| --- | --- |
| 2.5 | 21  |
| 3 | 3 |
| 4 | 6 |

The screw length allows slight variations, but stay within +5 mm of the given size.
The following screws are recommended for the assembly of the machine:

| Metric | Type | l (mm) | Qty |
| --- | --- | --- | --- |
| 2.5 | grub screw | ~5 | 8 |
| 2.5 | socket cap | 10 | 1 |
| 2.5 | socket cap | 12-15  | 4 |
| 3 | socket cap | 10-15  | 3 |
| 4 | socket cap | 5 | 4 |
| 4 | socket cap | 15-30  | 2 |

I usually use a one-stop shop for all screws and fasteners, like {{extra.screw_shop_link}}.

--8<-- "inserted_threads.md"

--8<-- "additional_parts.md"

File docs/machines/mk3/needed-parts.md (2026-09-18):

---
tags: [Machine]
---

# Needed Parts

Everything required to build the CocktailBerry MK III.

## Printed Parts (STLs)

--8<-- "machine/variants.md"

| Part | Qty | File | Notes |
| --- | --- | --- | --- |
| Bundler | 1 | Bundler | |
| Draining Rack | 1 | DrainingRack | |
| Funnel Bend | 1 | FunnelBend | default funnel  |
| Funnel Bend Small | 1 | FunnelBendSmall | optional funnel |
| Funnel Straight | 1 | FunnelStraight | optional funnel |
| Lid Tower | 1 | LidTower | |
| Monitor Bridge | 1 | MonitorBridge | |
| Pump Fixer | 8 | PumpFixer | optional |
| Tower Bottom | 1 | TowerBottom | |
| Tower Middle | 1 | TowerMiddle | default middle  |
| Tower Middle RingLED | 1 | TowerMiddleRingLED | optional middle |
| Tower Top | 1 | TowerTop | |
| Tube Fixer 40mm | 2 | TubeFixer40mm | optional |
| Tube Fixer 50mm | 2 | TubeFixer50mm | optional |

## Electronics

See also the [PCBAs](../../pcbas/index.md) section.

| Component | Qty | Notes |
| --- | --- | --- |
| CBB-GPIO  | 1 | I2C variant is fine as well |

## Hardware

| Item | Qty | Notes |
| --- | --- | --- |
| {{extra.pi_3bplus_link}} | 1 | Pi 4/5 needs a different HDMI cable |
| {{extra.sd_card_link}} | 1 | |
| {{extra.touch_7in_link}} | 1 | Case designed for this |
| {{extra.power_jack_2_5_mm_link}} | 1 | |
| {{extra.voltage_converter_link}} | 1 | |
| {{extra.power_supply_12v_link}} | 1 | |
| {{extra.membrane_pump_link}} | 8 | {{extra.membrane_pump_alt_link}} is also fine |
| {{extra.tubing_link}} | 5-10 m | 5×8 mm |
| {{extra.jumper_wires_link}} | 1 | 10 cm is long enough |
| {{extra.hex_standoffs_link}} | 16 | can use other height |
| {{extra.hdmi_cable_link}} | 1 | needs to be slim |
| {{extra.usb_cable_link}} | 1 | needs to be slim |
| {{extra.micro_usb_open_cable_link}} | 1 | |
| (Wooden) Base Plate ~40×40 cm | 1 | |
| {{extra.ring_led_12_link}} | 2 | *Optional* if using LED tower |

## Fasteners

For more information on the threaded inserts, see the section below.
The following inserts are required for the assembly of the machine:

| Metric | Qty |
| --- | --- |
| 2.5 | 8 |
| 3 | 4 |
| 4 | 3 |
| 5 | 1 |

The screw length allows slight variations, but stay within +5 mm of the given size.
The following screws are recommended for the assembly of the machine:

| Metric | Type | l (mm) | Qty |
| --- | --- | --- | --- |
| 2.5 | socket cap | 10 | 5 |
| 3 | flat | 15 | 2 |
| 3 | flat | 10 | 2 |
| 3 | grub screw | ~5 | 8 |
| 4 | socket cap | 10 | 3 |
| 5 | flat | 25 | 2 |

I usually use a one-stop shop for all screws and fasteners, like {{extra.screw_shop_link}}.

--8<-- "inserted_threads.md"

--8<-- "additional_parts.md"

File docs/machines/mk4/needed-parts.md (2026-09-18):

---
tags: [Machine]
---

# Needed Parts

Everything required to build the CocktailBerry MK IV.

## Printed Parts (STLs)

--8<-- "machine/variants.md"

| Part | Qty | File | Notes |
| --- | --- | --- | --- |
| Bundler | 1 | Bundler | |
| Draining Rack No Scale | 1 | DrainingRackNoScale | default rack |
| Draining Rack With Scale | 1 | DrainingRackWithScale | *variant* scale |
| Drip Tray No Scale | 1 | DripTrayNoScale | default tray |
| Drip Tray With Scale | 1 | DripTrayWithScale | *variant* scale |
| Load Cell Bottom Holder | 1 | LoadCellBottomHolder | *optional* scale |
| Load Cell Top Connector | 1 | LoadCellTopConnector | *optional* scale |
| Scale Electrics Socket | 1 | ScaleElectricsSocket | *optional* scale |
| Tablet Holder Plate | 1 | TabletHolderPlate | |
| Funnel | 1 | Funnel | default funnel |
| Short Funnel | 1 | ShortFunnel | *variant* funnel |
| Long Funnel | 1 | LongFunnel | *variant* funnel |
| LED Hole Plug | 1 | LedHolePlug | *optional* LED |
| Lid Top | 1 | LidTop | |
| Peristaltic Holder | 2 | PeristalticHolder | |
| Pump Tower Lid | 2 | PumpTowerLid | |
| Tube Fixer | 2 | TubeFixer | *optional* |
| Tower Top | 1 | TowerTop | |
| Tower Middle | 1 | TowerMiddle | |
| Tower Bottom No Scale | 1 | TowerBottomNoScale | default bottom |
| Tower Bottom No Scale LED | 1 | TowerBottomNoScaleLED | *variant* LED |
| Tower Bottom With Scale | 1 | TowerBottomWithScale | *variant* scale |
| Tower Bottom With Scale LED | 1 | TowerBottomWithScaleLED | *variant* scale LED |
| Power Cable Clip | 1 | PowerCableClip | *optional* |

Note that the tower comes in different variants, most notably at the bottom section.
There are 4 variants:

- plain
- with LED
- with scale
- with scale and LED

## Electronics

See also the [PCBAs](../../pcbas/index.md) section.

| Component | Qty | Notes |
| --- | --- | --- |
| CBB-I2C | 1 | GPIO variant is fine if no scale |

Note that the I2C board version is easier to install and integrate with the rest of the components.
You can always use the GPIO version if you prefer, but it will require more wiring.
If you do not use a scale, the GPIO version is still a good fit.

## Hardware

| Item | Qty | Notes |
| --- | --- | --- |
| {{extra.pi_5_link}} | 1 | {{extra.pi_4_link}} works as well |
| {{extra.sd_card_link}} | 1 | |
| {{extra.power_jack_2_5_mm_link}}  | 1 | |
| {{extra.voltage_converter_link}}  | 1 | |
| {{extra.power_supply_12v_link}} | 1 | |
| {{extra.membrane_pump_link}} | 8 | {{extra.membrane_pump_alt_link}} is also fine |
| {{extra.peristaltic_pump_link}} | 2 | |
| {{extra.tubing_link}} | 5-10 m | 5×8 mm |
| {{extra.tubing_link}} | 2 m | 3×5 mm |
| {{extra.jumper_wires_link}} | 1 | 10 cm is long enough |
| {{extra.hex_standoffs_link}} | 16 | can use other height |
| {{extra.usb_c_open_cable_link}} | 1 | |
| {{extra.lenovo_tab_link}} | 1 | Can use your phone instead |
| {{extra.magnet_6x3_link}} | 2 | |
| (Wooden) Base Plate ~40×40 cm | 1 | |
| {{extra.strip_led_link}} | 1 | *Optional* if using LED |
| {{extra.led_3pin_connector_link}} | 1 | *Optional* if using LED |
| {{extra.load_cell_link}} | 1 | *Optional* if using scale |
| {{extra.nau7802_link}} | 1 | *Optional* if using scale |

## Fasteners

For more information on the threaded inserts, see the section below.
The following inserts are required for the assembly of the machine:

| Metric | Qty |
| --- | --- |
| 2.5 | 12 or 16 (scale) |
| 3 | 14 |
| 4 | 3 |
| 5 | 2 |

The screw length allows slight variations, but stay within +5 mm of the given size.
The following screws are recommended for the assembly of the machine:

| Metric | Type | l (mm) | Qty |
| --- | --- | --- | --- |
| 2.5 | Socket cap | 10 | 4 |
| 3 | Socket cap | 10 | 10  |
| 3 | Socket cap | 10-15  | 2 |
| 3 | Flat | 10-12  | 2 |
| 4 | Socket cap | 25 | 3 |
| 5 | Flat | 25 | 2 |

For the scale, the following screws are required:

| Metric | Type | l (mm) | Qty |
| --- | ---- | --- | --- |
| 4 | Flat | 10-15  | 2 |
| 5 | Flat | 30 | 2 |

I usually use a one-stop shop for all screws and fasteners, like {{extra.screw_shop_link}}.

--8<-- "inserted_threads.md"

--8<-- "additional_parts.md"

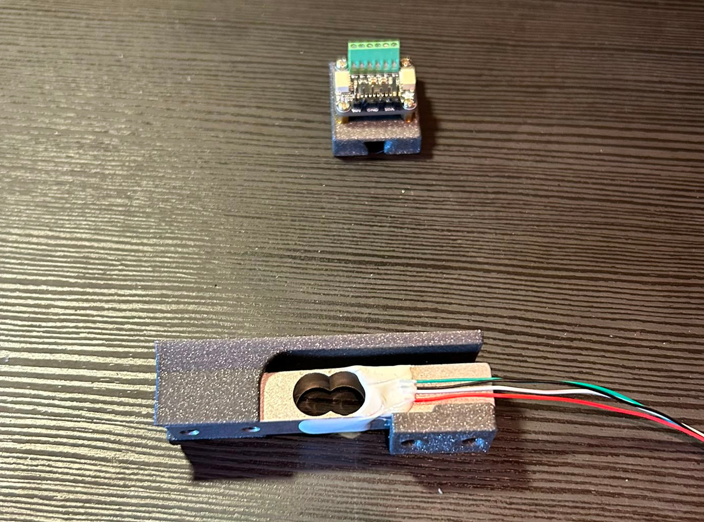
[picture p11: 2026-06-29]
docs/img/mk4/scale_parts.jpeg

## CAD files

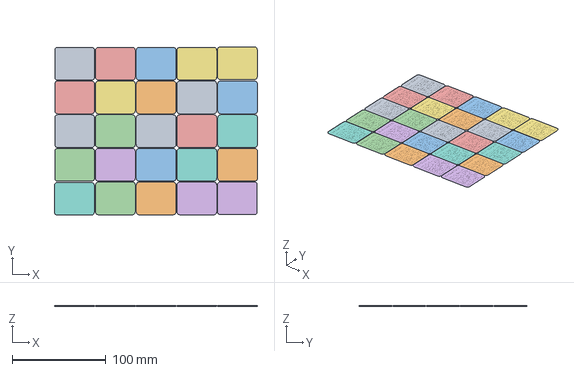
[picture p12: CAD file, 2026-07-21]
cad/accessories/CocktailBerryPagePlates.3mf
217.0 x 180.0 x 0.84 mm
combined-1755846965544.stl x 25

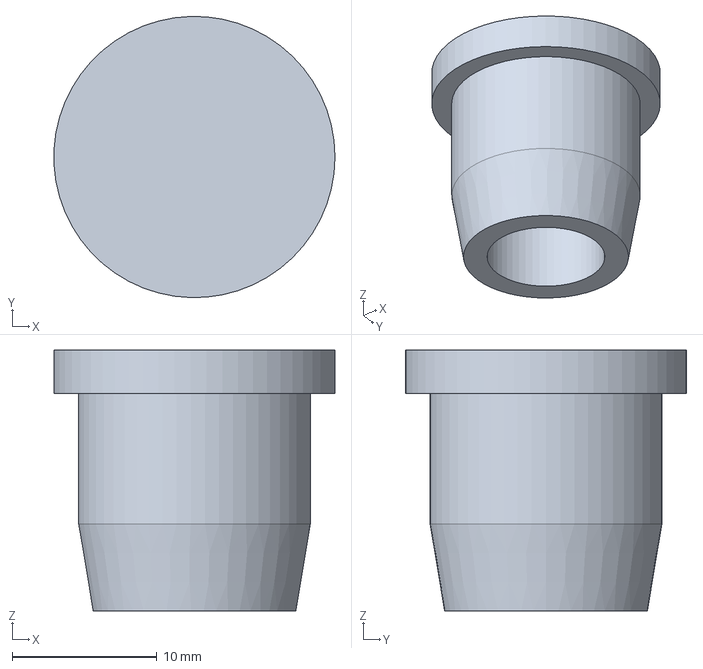
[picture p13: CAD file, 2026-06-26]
cad/machines/2go/FootPlugs.FCStd
19.4 x 19.4 x 18.0 mm

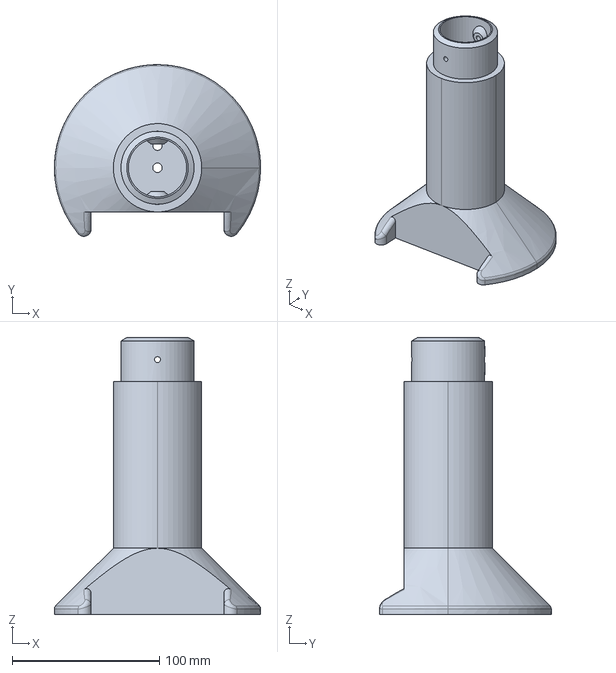
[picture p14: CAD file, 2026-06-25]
cad/machines/mk3/TowerBottom.FCStd
140.0 x 116.5 x 188.0 mm

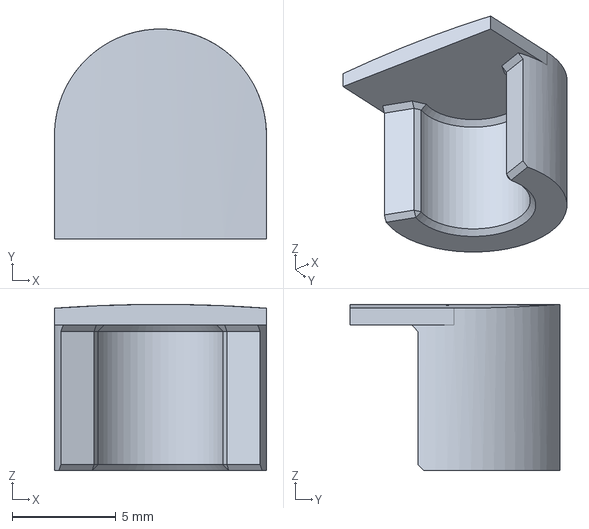
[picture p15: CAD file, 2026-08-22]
cad/machines/mk4/LedHolePlug.FCStd
10.2 x 10.1 x 8.00 mm

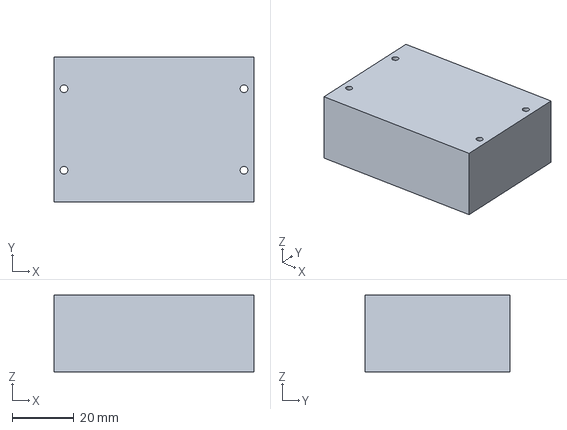
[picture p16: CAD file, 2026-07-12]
cad/machines/mk4/others/dummy_converter.FCStd
65.0 x 47.0 x 25.0 mm

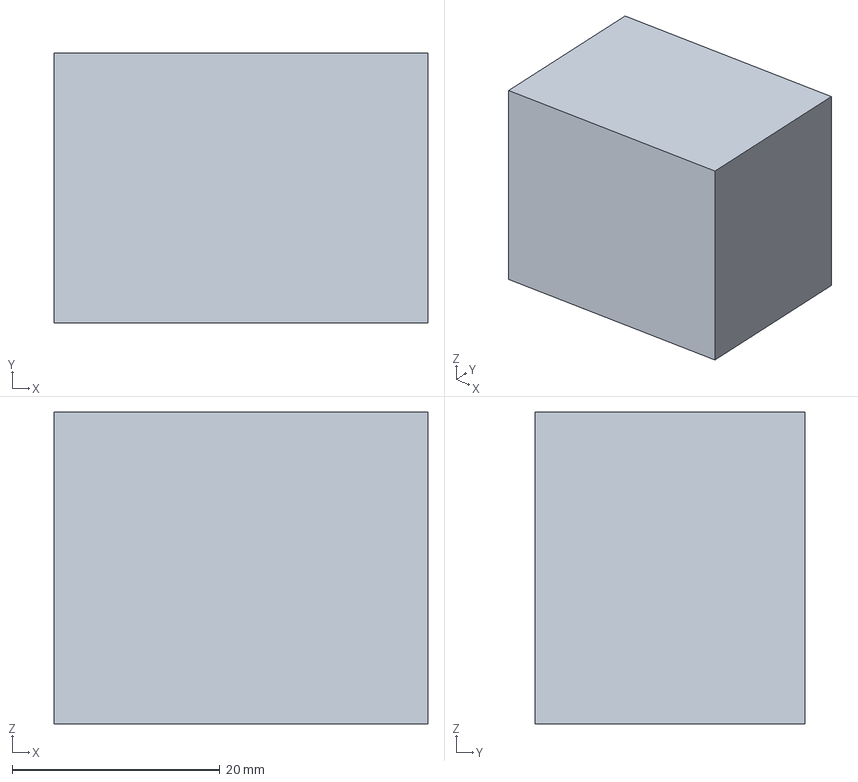
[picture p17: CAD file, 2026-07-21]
cad/accessories/PlateBox.FCStd
36.0 x 26.0 x 30.0 mm

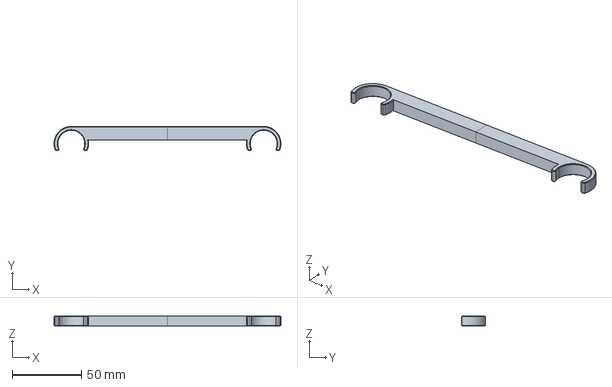
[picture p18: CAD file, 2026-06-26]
cad/machines/2go/LegStabilizers.FCStd
164.0 x 17.5 x 7.00 mm

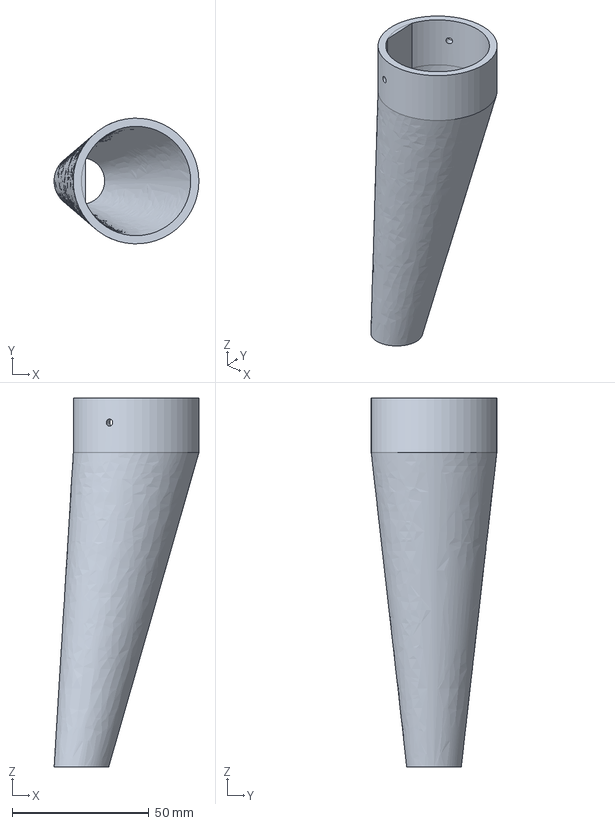
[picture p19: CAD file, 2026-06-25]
cad/machines/mk3/FunnelStraight.FCStd
53.0 x 46.0 x 135.0 mm

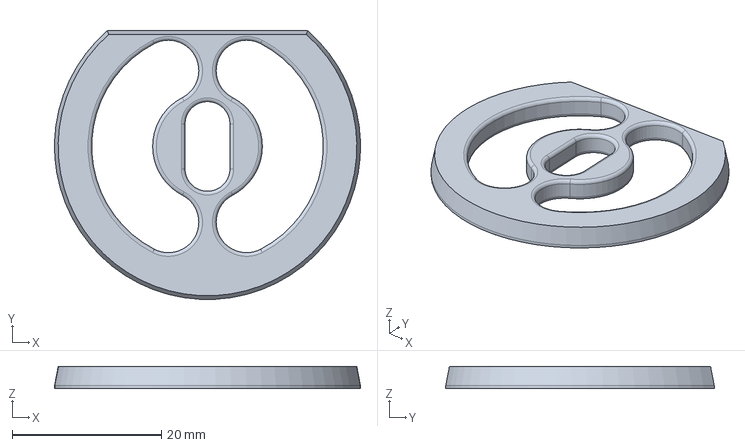
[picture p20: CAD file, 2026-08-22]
cad/machines/mk4/Bundler.FCStd
41.0 x 36.0 x 3.00 mm

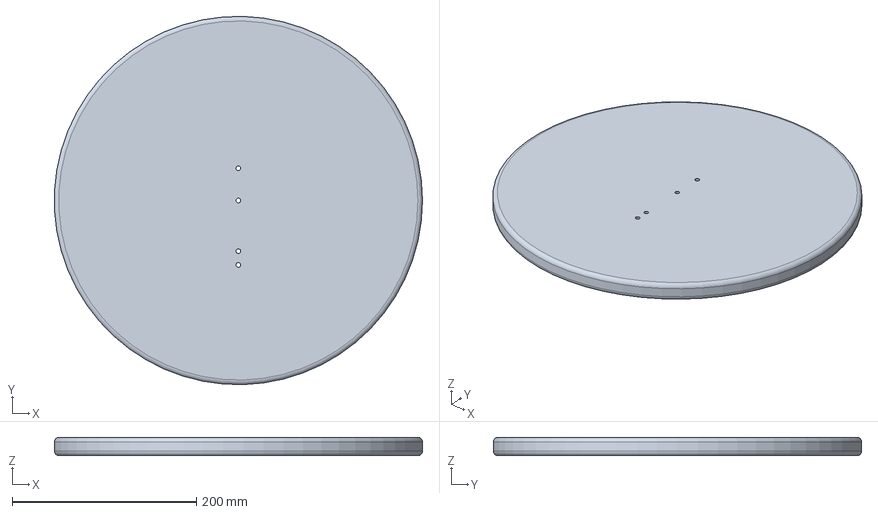
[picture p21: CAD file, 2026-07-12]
cad/machines/mk4/others/BasePlate.FCStd
399.7 x 399.8 x 20.0 mm

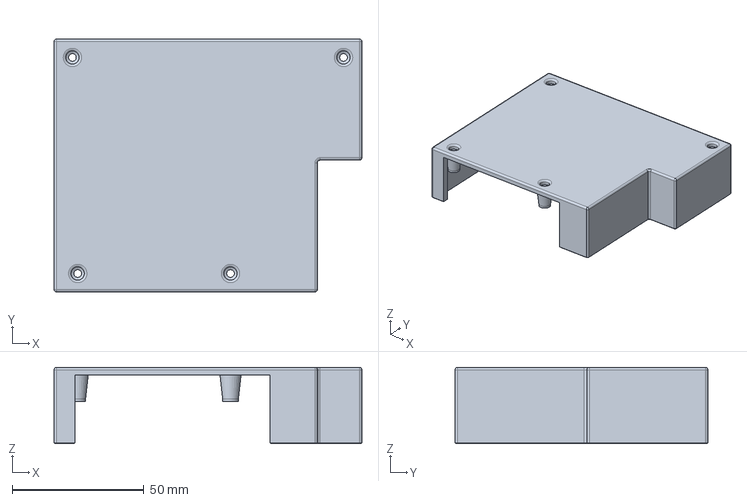
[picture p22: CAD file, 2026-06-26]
cad/machines/2go/ElectricLid.FCStd
116.9 x 96.0 x 29.0 mm

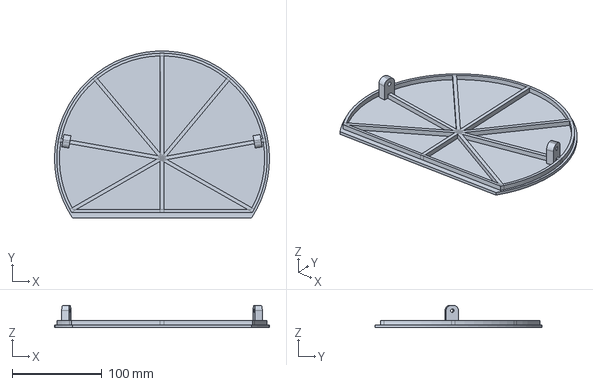
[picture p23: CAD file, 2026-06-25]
cad/machines/mk3/LidTower.FCStd
240.0 x 186.2 x 25.0 mm

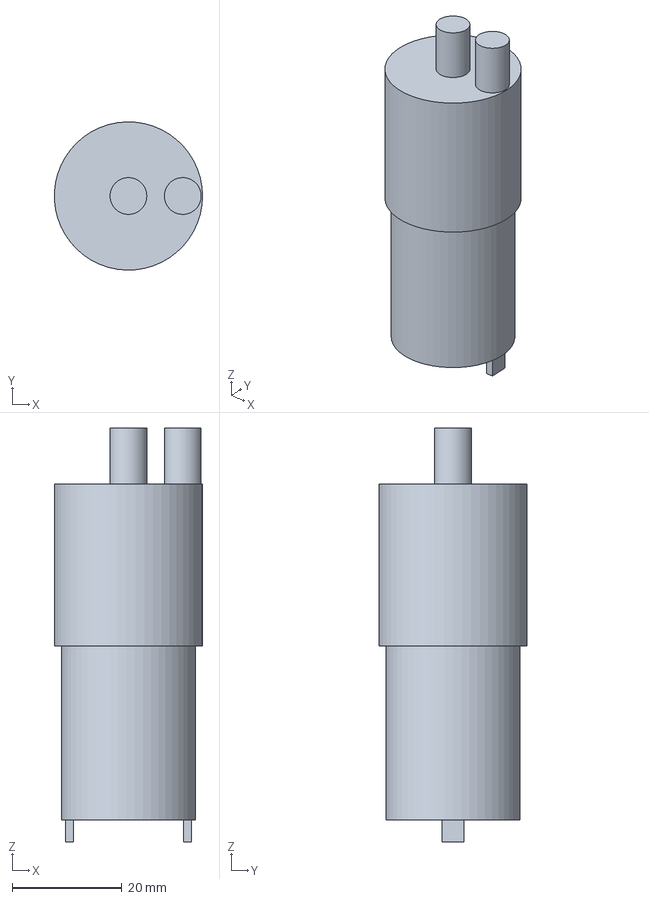
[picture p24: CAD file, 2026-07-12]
cad/machines/mk4/others/Pump.FCStd
27.0 x 27.0 x 75.4 mm

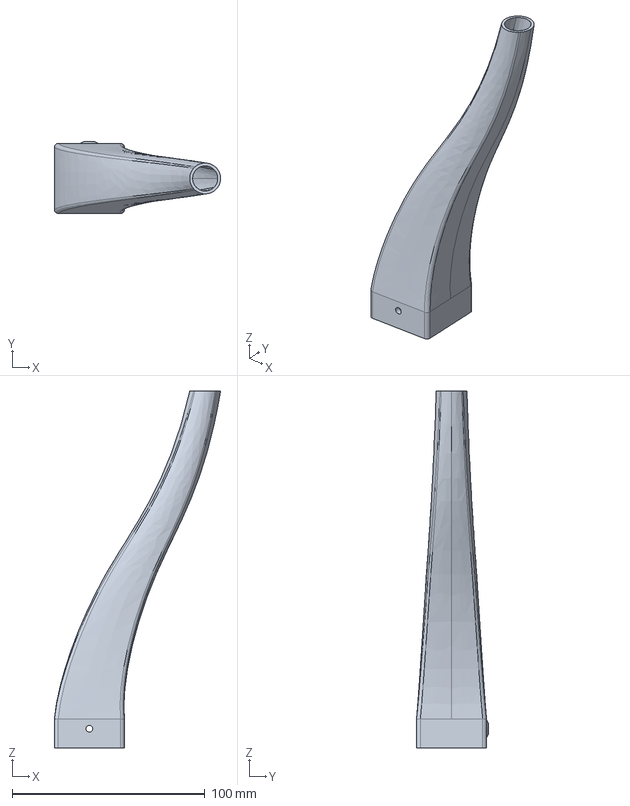
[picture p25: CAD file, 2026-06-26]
cad/machines/2go/Funnel.FCStd
86.2 x 37.3 x 185.0 mm

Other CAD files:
cad/machines/mk4/Parameters.FCStd
cad/machines/mk3/TowerMiddle.FCStd
cad/machines/mk4/Funnel.FCStd
cad/machines/mk4/others/Bottle.FCStd
cad/accessories/PlateBox.3mf
cad/machines/2go/FootTransport.FCStd
cad/machines/2go/LegHolder.FCStd
cad/machines/2go/PumpGrid.FCStd
cad/machines/mk3/Bundler.FCStd
cad/machines/mk3/DrainingRack.FCStd
cad/machines/mk3/DripTray.FCStd
cad/machines/mk3/FunnelBend.FCStd
cad/machines/mk3/FunnelBendSmall.FCStd
cad/machines/mk3/MonitorBridge.FCStd
cad/machines/mk3/PumpFixer.FCStd
cad/machines/mk3/TubeFixer40mm.FCStd
cad/machines/mk3/TubeFixer50mm.FCStd
cad/machines/mk4/DrainingRack.FCStd
cad/machines/mk4/DrainingRackWithScale.FCStd
cad/machines/mk4/DripTray.FCStd
cad/machines/mk4/DripTrayWithScale.FCStd
cad/machines/mk4/LidTop.FCStd
cad/machines/mk4/LoadCellBottomHolder.FCStd
cad/machines/mk4/LoadCellTopConnector.FCStd
cad/machines/mk4/PeristalticHolder.FCStd
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

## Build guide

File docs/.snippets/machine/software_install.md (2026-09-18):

Follow the instructions in the [CocktailBerry docs](https://software.cocktailberry.org/installation/) to install the software on the Raspberry Pi.
Uncheck the pins inverted option at the first program start - the board is inverted compared to a normal relay board, so with the wrong setting all pumps will run as soon as the program starts.
If you use the I2C version of the CocktailBerry Board, add and enable an MCP23017 board (default address 0x27) in the software settings.
Select *DC over I2C* as the pump type for all pumps, pin 0 is for pump 1 up to pin 9 for pump 10.

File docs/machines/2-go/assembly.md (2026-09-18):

---
tags: [Machine]
---

# Assembly

Step-by-step assembly of the CocktailBerry 2-Go.

--8<-- "machine/image_support.md"

## Step 1 - Drill Holes in Casing

The casing needs some holes for the parts to be mounted inside.
There is no exact measurement for the holes, the parts should be placed and then the hole position marked and drilled.
Drill two 4 mm holes on each short side for the leg holders.
Drill two 4 mm holes on the back side and one 3 mm hole on the front side for the pump grid combined with the electric lid (this can be done after the pump grid is mounted).
If a monitor is used, cut a rectangular opening and drill the 2.5 mm monitor holes in the front.
Drill a hole on the back side for the power jack (12 V), at the side where the converter will be placed.

## Step 2 - Mount the Pumps

Put all 8 pumps in the pump grid, power connection facing the extensions with the M4 threads.
Use the M2.5 grub screws to fix the pumps in the grid.
Both of the power supply connections should be parallel to the long side of the grid.

## Step 3 - Mount the Main Board

The main board is mounted on the top of the pump grid with two M3 screws.
The long part should point in the direction of the pump outlet.

## Step 4 - Connect the Tubing

The pumps in the grid are placed in a "zig-zag" pattern, so the tubing can be connected in a way that the tubes do not cross each other.
Use the first 4 pumps to connect to the left side, the second 4 to connect to the right side of the numbered inlets.
The tubing should be long enough to reach the bottom of the bottle when the machine is assembled, keep it a little bit longer than needed.
Try to match each numbered inlet to the inlet of the corresponding pump.
Connect the outlet tubes to the pump outlets.
You can use some tape to fix all tubes together at the machine outlet, so they can't slip back.

## Step 5 - Mount the PCBAs + SBC

Mount 8 hex standoffs (M2.5) on the main board, forming two rectangles, one for the CocktailBerry Slim board and one for the Raspberry Pi.
Mount the CocktailBerry Slim board on the main board, screw only two inner corners.
Do the same with the Raspberry Pi, mount it on the main board with 4 hex standoffs (M2.5) and screw only two inner corners.
Mount the converter onto the leg holder with the threaded inserts.

## Step 6 - Connect the Pumps

Solder the pump wires to the CocktailBerry Slim board, red to + and black to -.
Connect the GPIO pins of the Raspberry Pi to the CocktailBerry Slim board with jumper wires.

--8<-- "machine/gpio_pins.md"

## Step 7 - Connect the Power

Connect the power jack to the 12 V input of the CocktailBerry Slim board.
The 12 V output of the board should be connected to the input of the voltage converter, and the 5 V output of the converter should be connected to the Raspberry Pi.
Keep the wires long enough that they can be routed inside the casing, once mounted.

## Step 8 - Assemble the Casing

Mount the pump grid + main board combination into the casing, also both sides of the leg holders.
Use the matching screws from the outside of the casing to fix the parts in place.
Fix the power jack into the casing, so it doesn't move.
*Optional*: Connect the HDMI and USB cables from the touchscreen to the Raspberry Pi.
Use the M2.5 screws to fix the touchscreen to the casing, if a touchscreen is used.
Put the electric lid on the casing and fix it with the M2.5 screws.
The funnel can be attached to the main board, fixed with one M2.5 screw, so it doesn't move.
It can be removed the same way for transportation or cleaning.

<figure markdown>
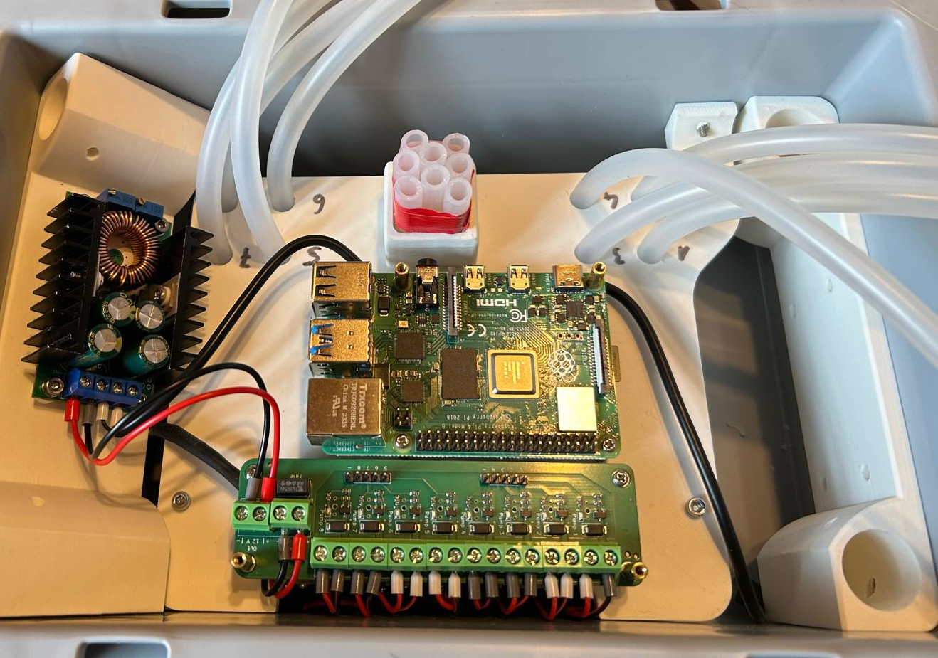
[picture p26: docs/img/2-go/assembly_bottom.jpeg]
Mounting inside the casing
  
  <figcaption>Mounting inside the casing (no screen)</figcaption>
</figure>

## Step 9 - Installation of Software

--8<-- "machine/software_install.md"

--8<-- "machine/final_checks.md"

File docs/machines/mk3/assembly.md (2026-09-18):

---
tags: [Machine]
---

# Assembly

Step-by-step assembly of the CocktailBerry MK III.

--8<-- "machine/image_support.md"

## Step 1 - Prepare the Base Plate

You need to drill one 5 (+0.1) mm hole into the center of the base plate and one 15 mm away from the center, toward the back of the plate.

## Step 2 - Assemble the Tower

Solder wires to the power jack; they need to be long enough to reach from the jack hole in the back of the middle tower up into the top tower.
Mount the jack into the middle tower, put the wires through the top hole into the tower.

Start by screwing the Tower Bottom to the base plate using the M5 insert and an M5 screw.
Then stack the Tower Middle and screw it to the bottom part using M3 screws.
Put the Tower Top on and screw it to the middle part using M4 screws.
Insert the Bundler from the top into the top tower using its profile and glue it in place.

## Step 3 - Mount the Pumps

Cut the tubing for the pump inlet, it should be a little longer than the distance from the base plate to the top of the pump socket.
Connect the pump with the tubing, insert the tubing into one pump socket.
Push another tube through the outlet and connect it to the pump.
Place the pump into the socket, guide the outlet tube through the bundler.
Cut the outlet tube, leaving some distance to the end of the bundler.
Repeat this for all pumps, try to route each outlet tube to its position in the bundler, so they don't cross each other.

When the tubes do not lie snugly, you can use the optional pump fixer to fix them in place, parallel to the bottom of the tower.
You can use some tape to fix all tubes together at the machine outlet, so they can't slip back.
Put the funnel to the bundler and use one screw to fix it in place, so it doesn't move.

## Step 4 - Mount Electronics

Mount the CocktailBerry Board on the top tower (middle) using M2.5 hex standoffs.
Use as much distance as you need to not collide with the tubes.
Fix the board with more M2.5 standoffs on the top, so it doesn't move.
Do not use screws, since we add the Raspberry Pi on top of the board later.
Do the same with the converter on the inner back side of the tower.

## Step 5 - Solder the Pumps

If the pumps do not come with wires attached, solder them on; otherwise skip this step.
Make sure the wire from each pump is long enough to reach the board, and solder the wires to the corresponding pump socket on the board.

## Step 6 - Wiring of Electronics

For all the screw terminals, you can use the crimp connectors to make the wire connection easier and more secure, but this is an optional step.

The Power Jack needs to be connected to the 12 V input of the CocktailBerry Board.
The 12 V output of the board should be connected to the input of the voltage converter, and the 5 V output of the converter should be connected to the Raspberry Pi.
Connect each pump to a matching +/- pump output on the CocktailBerry Board.
For easier setup, try to connect the pumps in order (for example, pump 1 to the first pump socket, pump 2 to the second, etc.).

## Step 7 - Mount the Touchscreen

Mount the touchscreen on the monitor bridge using the screws and nuts.
Glue the monitor bridge to the top of the tower, make sure to align it properly so the screen is centered and straight.
You can use the bottom screws for the monitor to achieve this.

## Step 8 - Mount the RPi

Mount the Raspberry Pi on top of the CocktailBerry Board using the M2.5 hex standoffs and screws.
If the standoffs are too short, stack a second one on top.
You can also do step 9 first (GPIO connections) and then mount the RPi, since the GPIO connections are easier to access without the RPi in place.

## Step 9 - Connect Signals

Connect the GPIO pins with the GND and pump 1-8 pins of the board using jumper wires.

--8<-- "machine/gpio_pins.md"

Connect the HDMI and USB cables from the touchscreen to the Raspberry Pi.

<figure markdown>
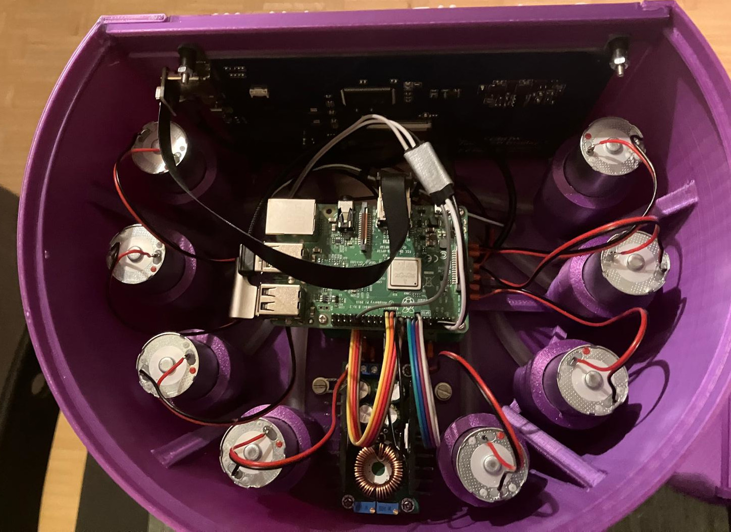
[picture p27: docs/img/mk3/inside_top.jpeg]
Top view
  
  <figcaption>Top view inside the machine</figcaption>
</figure>

## Step 10 - Installation of Software

--8<-- "machine/software_install.md"

--8<-- "machine/final_checks.md"

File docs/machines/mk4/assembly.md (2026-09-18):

---
tags: [Machine]
---

# Assembly

Step-by-step assembly of the CocktailBerry MK IV.

--8<-- "machine/image_support.md"

## Step 1 - Prepare the Base Plate

You need to drill two 5 (+0.1) mm holes along a line through the center of the base plate.
If you use a scale, you need to drill two additional 5 (+0.1) mm holes for the scale mounting.
Drill a chamfer for the countersunk heads into the holes.

<figure markdown>
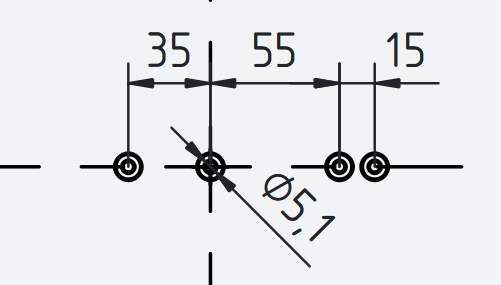
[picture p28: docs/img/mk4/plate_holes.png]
Plates Position
  
  <figcaption>Position of plate holes, right ones are optional</figcaption>
</figure>

## Step 2 - Assemble the Tower

Solder wires to the power jack; they need to be long enough to reach from the jack hole in the back of the middle tower up into the top tower.
Mount the jack into the middle tower, put the wires through the top hole into the tower.

Start by screwing the Tower Bottom to the base plate using the two M5 inserts and M5 screws.
If using a scale, see [scale wiring](#optional-scale-wiring) and for LEDs see [LED wiring](#optional-led-wiring).

Stack the middle tower onto the bottom part and screw it to the bottom part using M3 screws.
If there are cables coming from the bottom tower, make sure to guide them through the middle tower.
Put the Tower Top on and screw it to the middle part using M4 screws.
Also guide all cables through the top tower, so they can be connected to the board later.
Insert the Bundler from the top into the top tower using its profile and glue it in place (*optional*, can also just friction fit).

## Step 3 - Mount the Pumps

Cut the tubing for the pump inlet, it should be a little longer than the distance from the base plate to the top of the pump socket.
As an alternative, you can use both ends of the tubing and cut it later after each pump is placed.
This requires one long (5-10 m) piece of tubing, which is usually what you buy anyway.

### Membrane Pumps

The membrane pumps use the 5×8 mm tubing and are mounted into the kidney-shaped pump sockets.
Connect the pump with the tubing, insert the tubing into one pump socket.
Push another tube from the middle tower through the bundler and the outlet, connect it to the pump.

<figure markdown>
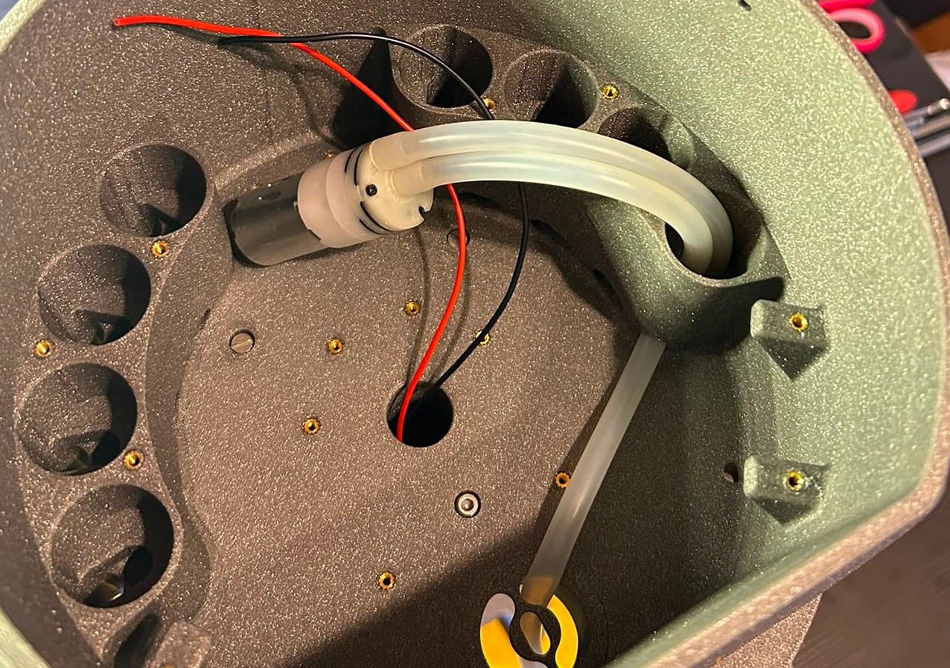
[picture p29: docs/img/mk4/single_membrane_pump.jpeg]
Single Membrane Pump Assembly
  
  <figcaption>Single membrane pump</figcaption>
</figure>

Place the pump into the socket, gently pull the tubing to ensure it is secure.
Cut the outlet tube, leaving some distance to the end of the outlet (~5 cm).
Repeat this for all membrane pumps, try to route each outlet tube to its position in the bundler, so they don't cross each other.

<figure markdown>
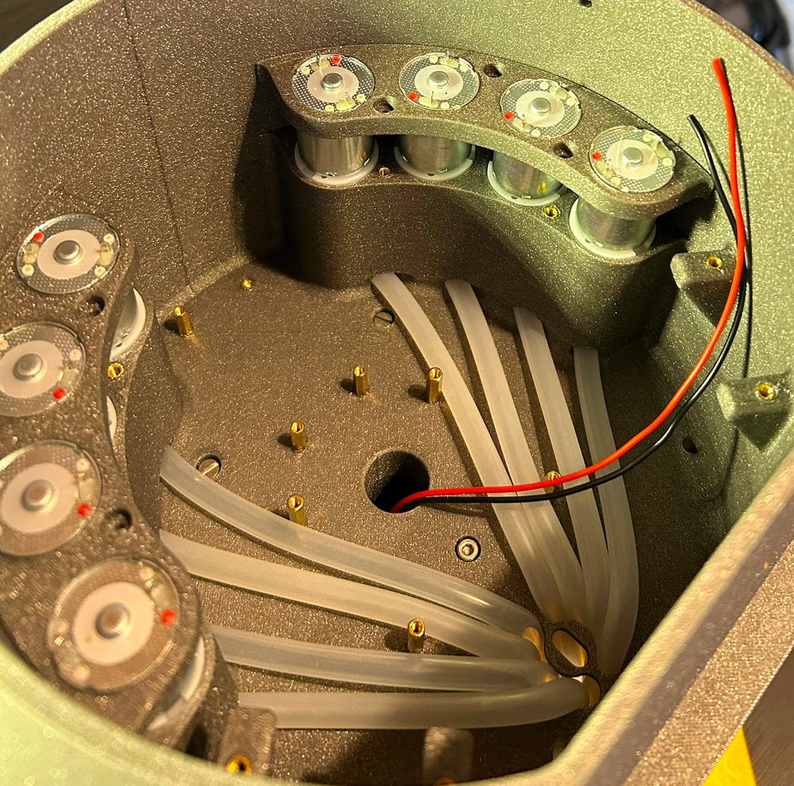
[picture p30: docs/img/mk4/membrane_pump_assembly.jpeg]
Membrane Pump Assembly
  
  <figcaption>Membrane pump assembly, top view</figcaption>
</figure>

When the tubes do not lie snugly, you can use the optional tube fixer to fix them in place, parallel to the bottom of the tower (should only concern membrane pumps).

<figure markdown>
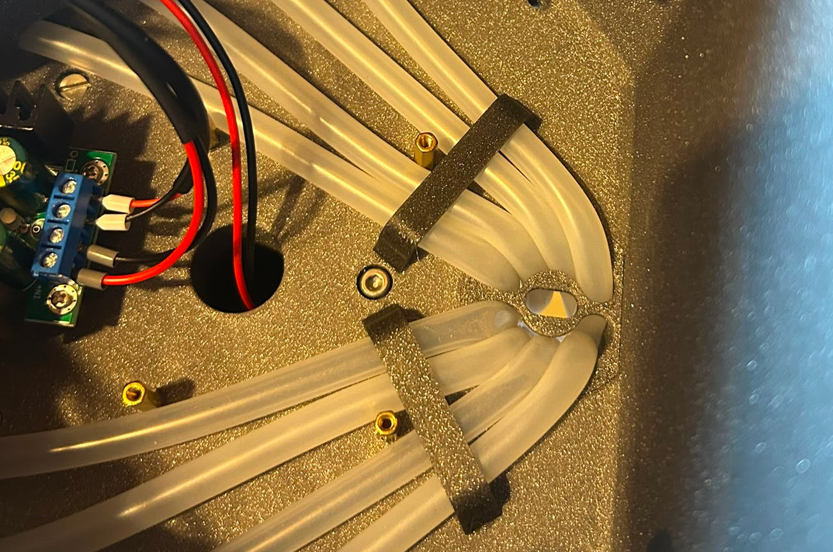
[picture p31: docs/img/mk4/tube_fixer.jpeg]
Tube Fixer
  
  <figcaption>Tube fixer, top view</figcaption>
</figure>

### Peristaltic Pumps

The peristaltic pumps use the 3×5 mm tubing and are mounted into the elevated pump holders in the front.
First, screw the peristaltic pump into the pump holder using the M2.5 screws.
The tubing should point away from the top of the U-shape.

<figure markdown>
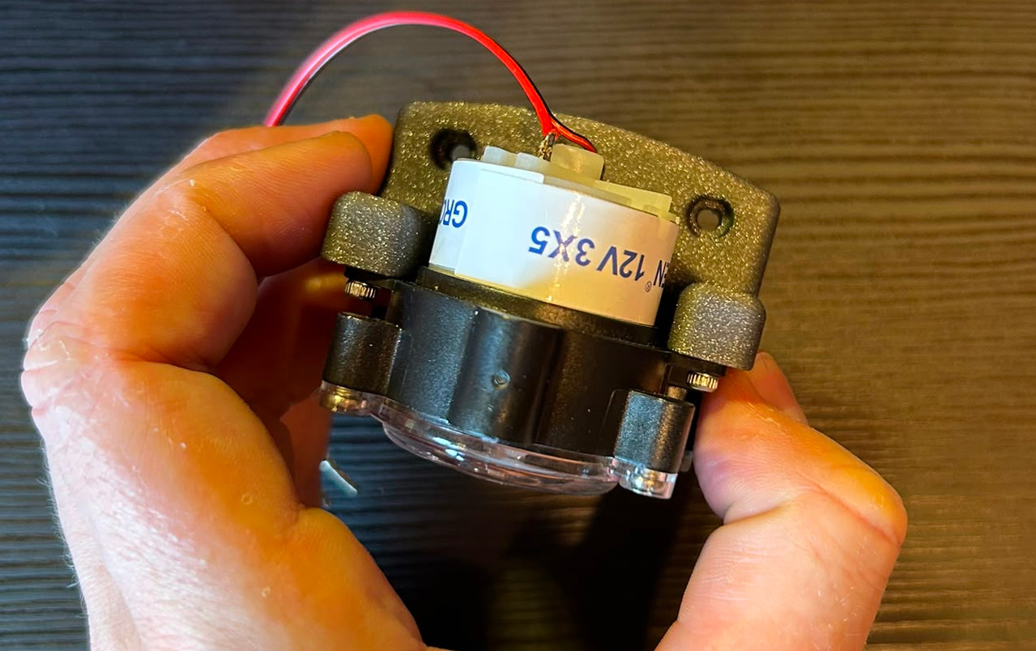
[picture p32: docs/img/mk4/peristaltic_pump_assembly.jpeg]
Peristaltic Pump Assembly
  
  <figcaption>Peristaltic pump assembly, top view</figcaption>
</figure>

It is strongly recommended to solder the wires to the pump before mounting it into the tower.
Then proceed to connect the input and output tubing as described for the membrane pumps.
Mount the pump holder into the tower using the M3 screws.

### Wrap-Up

You can use some tape to fix all tubes together at the machine outlet, so they can't slip back.
Then you can cut the outlet tubes short and in identical length, so they do not block the funnel.

<figure markdown>
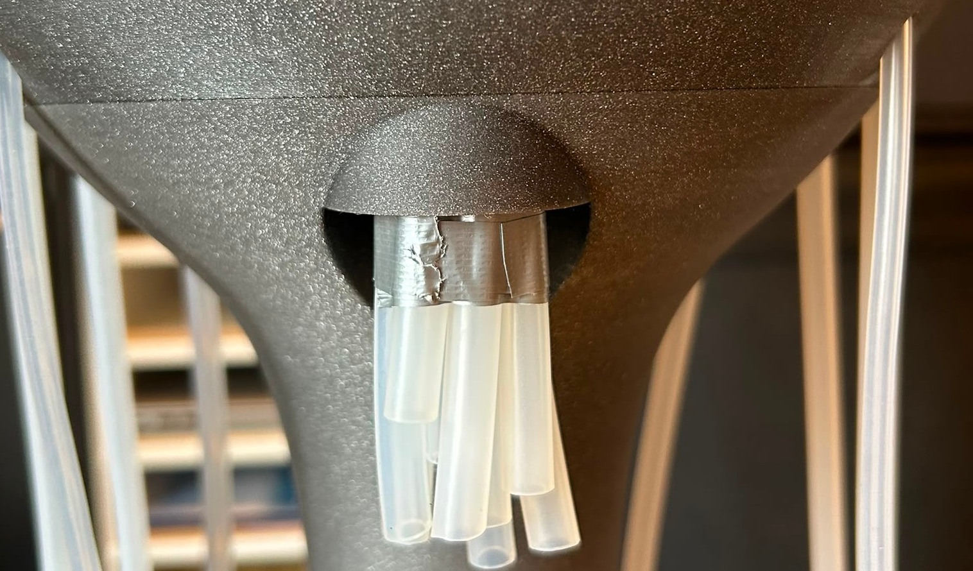
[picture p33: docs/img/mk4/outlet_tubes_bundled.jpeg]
Outlet Tubes Bundled
  
  <figcaption>Outlet tubes bundled, top view</figcaption>
</figure>

Push the funnel to the bundler until the magnet holds.
Fix the membrane pumps with the pump tower lid (see figure "*Membrane pump assembly, top view*"), which is screwed to the top of the tower using M3 screws.

<figure markdown>
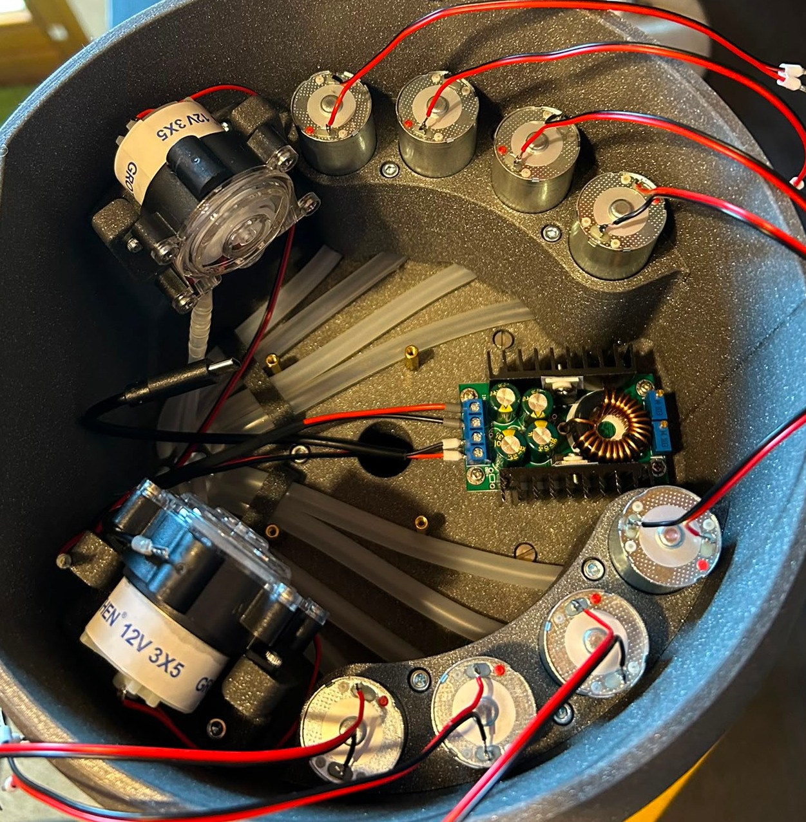
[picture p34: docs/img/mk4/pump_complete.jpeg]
Pump Complete
  
  <figcaption>Pump assembly complete, top view</figcaption>
</figure>

## Step 4 - Mount Electronics

Mount the voltage converter in the back between the pumps using M2.5 hex standoffs and screws.
You can use shorter standoffs for the converter and longer for the CocktailBerry Board, so the converter is lower than the board.
You can already connect the Raspberry Pi power cable, as well as one cable long enough to reach the CocktailBerry Board power output.
This is easier to do now, while the tower is still mostly empty.

<figure markdown>
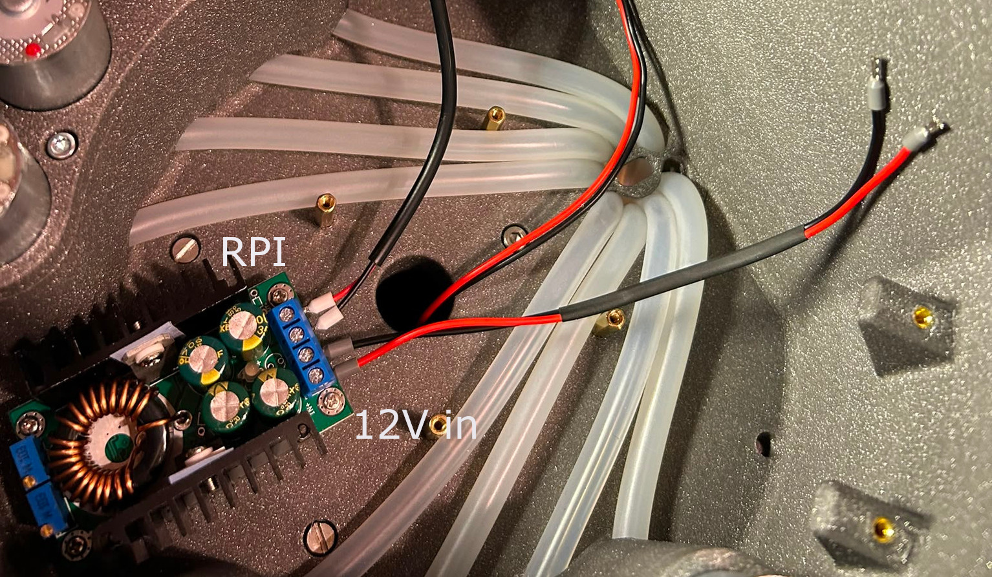
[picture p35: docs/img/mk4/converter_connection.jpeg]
Converter Connection
  
  <figcaption>Converter connection, top view</figcaption>
</figure>

Mount the CocktailBerry Board on the top tower (middle) using M2.5 hex standoffs.
Use as much distance as needed to not collide with the tubes.
Fix the board with more M2.5 standoffs on the top, so it doesn't move.
Do not use screws, since we add the Raspberry Pi on top of the board later.

## Step 5 - Solder the Pumps

If the pumps do not come with wires attached, solder them on; otherwise skip this step.
Make sure the wire from each pump is long enough to reach the board, and solder the wires to the corresponding pump socket on the board.
For peristaltic pumps, the polarity matters, so make sure to solder it so the pump runs in the outlet direction of the tubing.

## Step 6 - Wiring of Electronics

For all the screw terminals, you can use the crimp connectors to make the wire connection easier and more secure, but this is an optional step.

The Power Jack needs to be connected to the 12 V input of the CocktailBerry Board.
The 12 V output of the board should be connected to the input of the voltage converter, and the 5 V output of the converter should be connected to the Raspberry Pi.
Connect each pump to a matching +/- pump output on the CocktailBerry Board.
For easier setup, try to connect the pumps in order (for example, pump 1 to the first pump socket, pump 2 to the second, etc.).
It is recommended to first connect everything to the CocktailBerry Board before mounting it into the tower, since it is easier to access the screw terminals without the tower in the way.

If you use a scale, connect it either to the I2C of the CocktailBerry Board or to the GPIO of the Raspberry Pi (next step), depending on which board you have.

## Step 7 - Mount the RPi

Mount the Raspberry Pi on top of the CocktailBerry Board using the M2.5 hex standoffs and screws.
If the standoffs are too short, stack a second one on top.
You can also do step 8 first (CocktailBerry Board connections) and then mount the RPi, since the GPIO connections are easier to access without the RPi in place.

## Step 8 - Connect Signals

If you use the I2C version of the CocktailBerry Board, just connect the I2C (3V3, GND, SDA, SCL) of the Raspberry Pi to the I2C of the CocktailBerry Board.

Otherwise, connect the GPIO pins with the GND and pump 1-10 pins of the board using jumper wires.

--8<-- "machine/gpio_pins.md"

If you have an LED, connect it to the GND, 5 V and GPIO (10 preferred) of the Raspberry Pi.

<figure markdown>
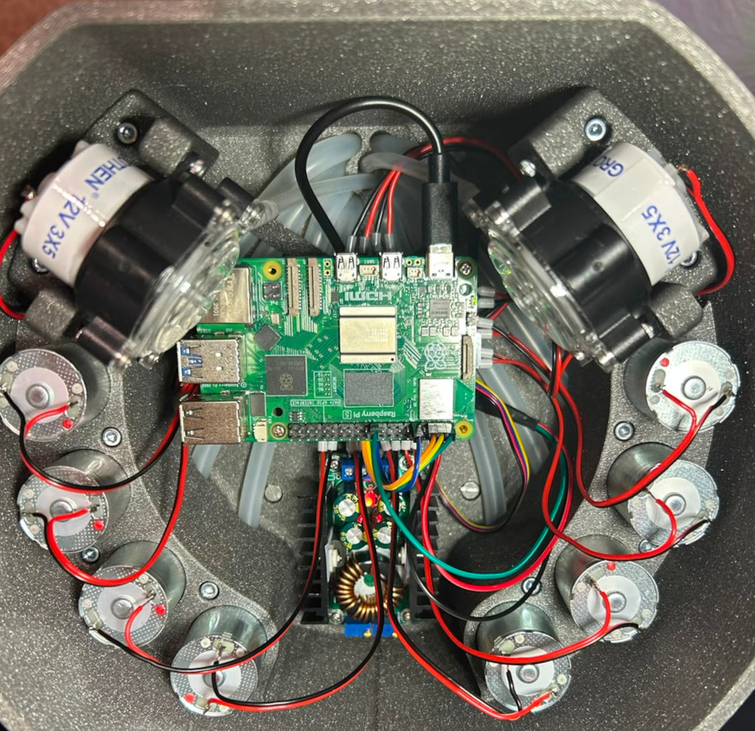
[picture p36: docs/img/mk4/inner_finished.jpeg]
Inner Finished
  
  <figcaption>Inner finished, top view</figcaption>
</figure>

## Step 9 - Glue the Plate

Apply some glue to the front of the top tower to fix the tablet holder plate in place.
It should be symmetrically aligned with the tower, so the tablet can be placed in the middle of the tower.
You can let it overlap as much as you want on the top, 5 mm is recommended, but it is not critical.

<figure markdown>
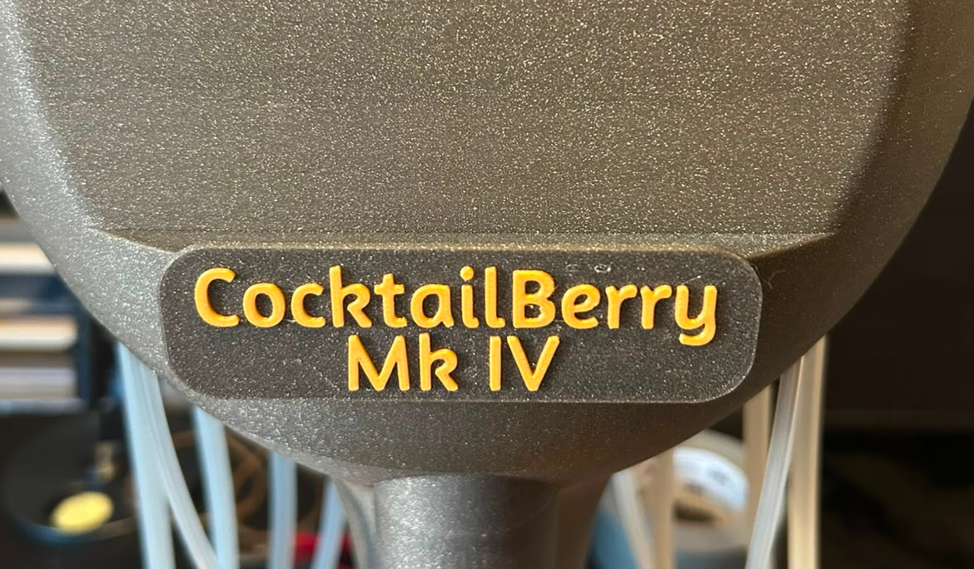
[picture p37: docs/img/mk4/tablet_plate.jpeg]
Tablet Holder
  
  <figcaption>Tablet holder plate, front view</figcaption>
</figure>

## Step 10 - Installation of Software

--8<-- "machine/software_install.md"

## Step 11 - Finalization

Now you can put the Lid Top on top of the tower and screw it in place using M3 screws.
Put the drip tray with the draining rack in the corresponding cutout at the bottom tower.
Place a bottle to each slot and adjust the length of the inlet tubing to reach the bottom of the bottles.
The machine is now ready to be connected to the power supply and can be used.

## *Optional* Scale Wiring

The load cell is screwed into the plate with two M5 screws, with the bottom holder in between.
The cable of the scale needs to point to the center of the plate/tower.
Then screw the top connector onto the load cell using two M4 screws.
The cable of the load cell needs to be pushed through the hole in the bottom tower.
Most load cells will not have a long enough cable, so you need to solder an extension there.
It should be long enough to reach out of the bottom tower.

<figure markdown>
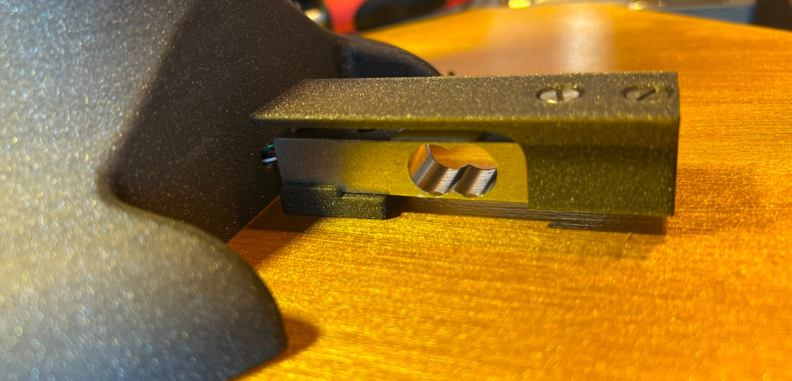
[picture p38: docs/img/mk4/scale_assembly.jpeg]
Scale Assembly
  
  <figcaption>Scale assembly, bottom view</figcaption>
</figure>

Screw the scale board onto the scale electronics socket using the M2.5 screws and slide it into the fitting socket in the tower.
Connect the load cell to the scale board (Red: E+, Black: E-, White: A-, Green: A+), and attach the connection cable for the CocktailBerry Board/Raspberry Pi now.
It will be guided through the tower to the top later, so it can be connected to the board.

<figure markdown>
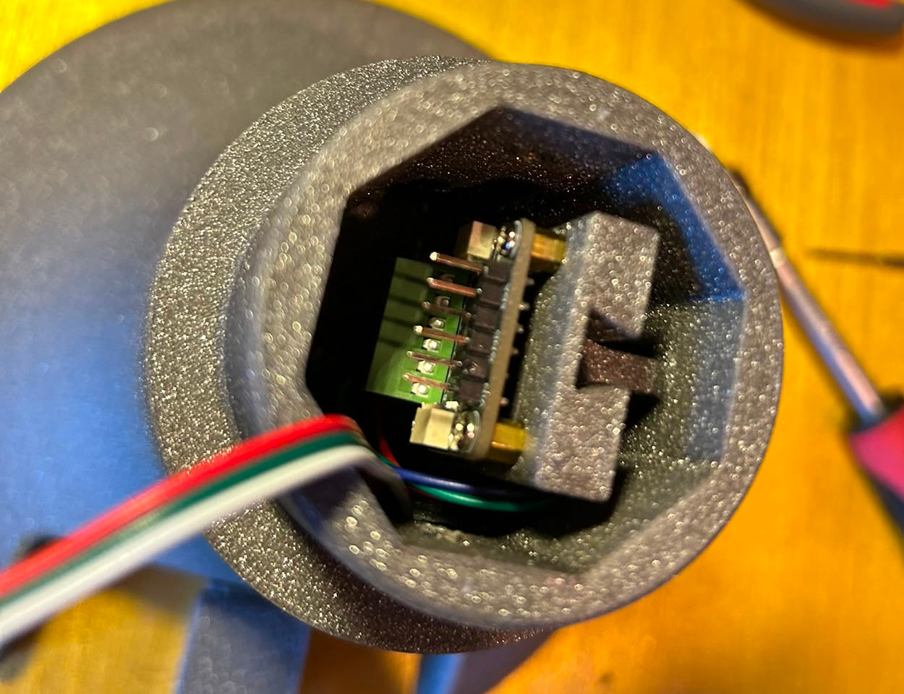
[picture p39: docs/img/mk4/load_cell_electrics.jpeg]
Scale Electrics
  
  <figcaption>Electrics in tower</figcaption>
</figure>

## *Optional* LED Wiring

It is recommended not to solder the LED before pushing the cable through the tower, since it is a tight fit.
Push the LED cable through the tower, and solder it to the LED strip.
Place the LED into the socket in the tower, touching the bottom of the cutout.
Put the LED hole plug into the tower, hiding the hole for the cable.
I recommend using a connector cable for the LED, so you can disconnect the LED from the middle point of the tower, when you need to disassemble the tower later.
Otherwise you can also use a long enough cable to the top of the tower.
In each case, attach the mating connector now.
It can be guided through the tower to the top, so it can be connected to the board later.

<figure markdown>
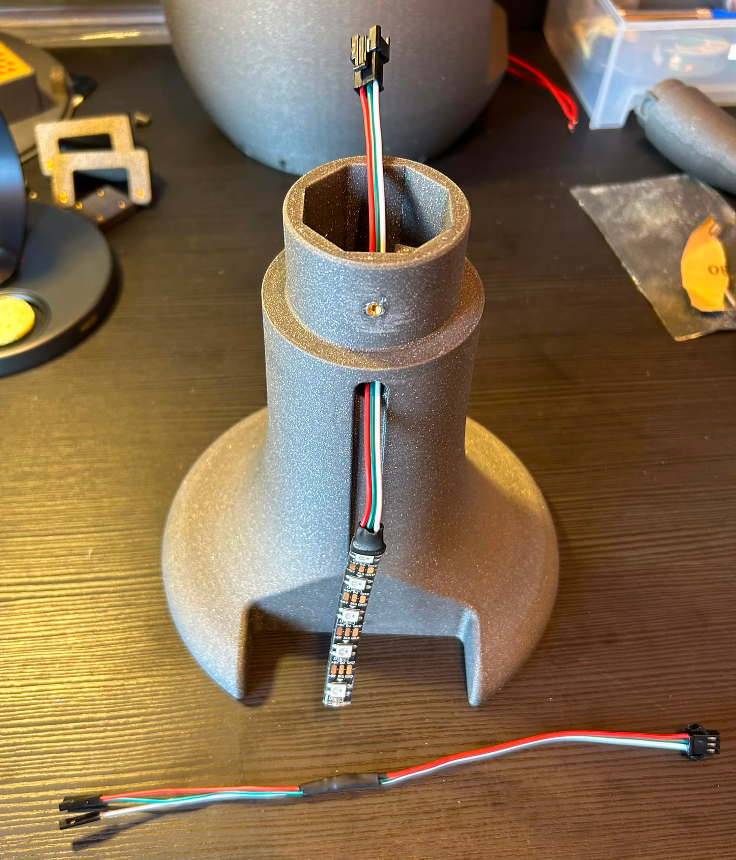
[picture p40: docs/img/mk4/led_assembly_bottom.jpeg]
LED Assembly
  
  <figcaption>LED assembly, bottom view</figcaption>
</figure>

--8<-- "machine/final_checks.md"

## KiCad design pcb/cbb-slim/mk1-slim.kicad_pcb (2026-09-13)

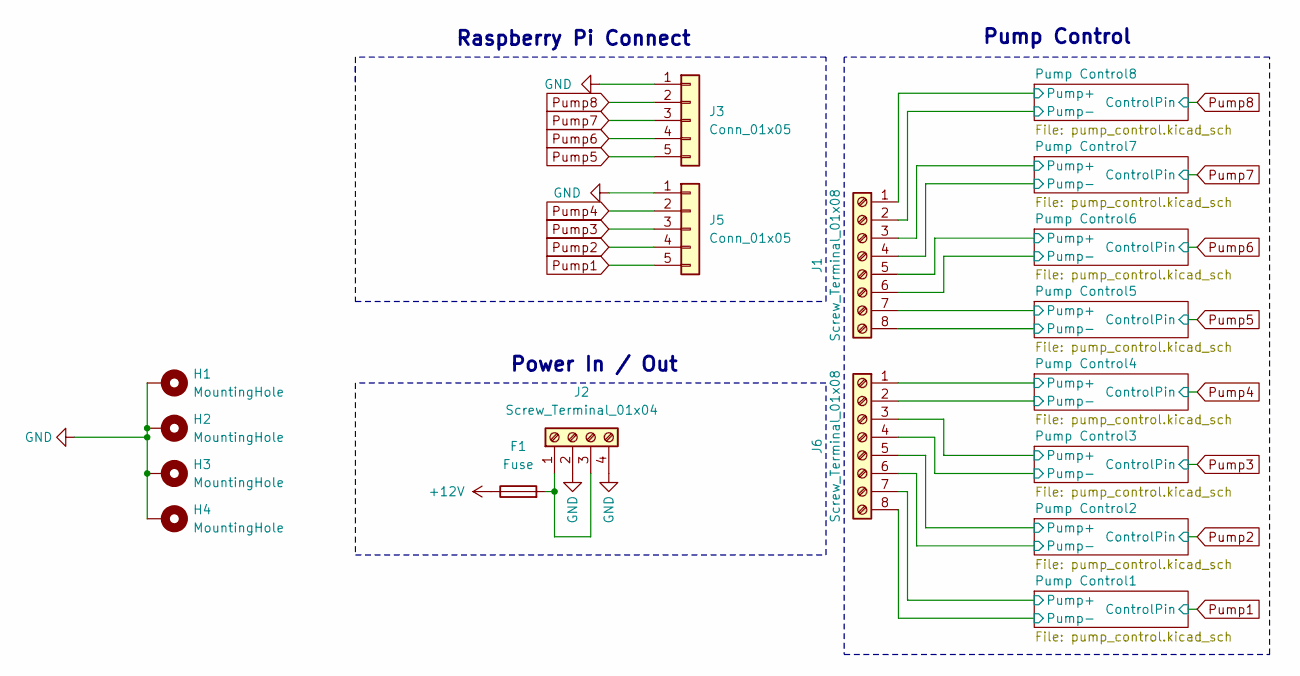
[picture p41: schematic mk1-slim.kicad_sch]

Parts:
F1: Fuse; Fuse_Littelfuse_395Series; MPN C22396288
H1, H2, H3, H4: MountingHole; MountingHole_2.7mm_M2.5_ISO7380_Pad
J1, J6: Screw_Terminal_01x08; TerminalBlock_Phoenix_MKDS-1,5-8_1x08_P5.00mm_Horizontal; MPN C430626
J2: Screw_Terminal_01x04; TerminalBlock_Phoenix_MKDS-1,5-4_1x04_P5.00mm_Horizontal; MPN C430624
J3, J5: Conn_01x05; PinSocket_1x05_P2.54mm_Vertical; MPN C124379

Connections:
+12V: F1.1, J1.1, J1.3, J1.5, J1.7, J6.1, J6.3, J6.5, J6.7; also elsewhere on the board
/Pump Control1/Pump-: J6.8; also elsewhere on the board
/Pump Control2/Pump-: J6.6; also elsewhere on the board
/Pump Control3/Pump-: J6.4; also elsewhere on the board
/Pump Control4/Pump-: J6.2; also elsewhere on the board
/Pump Control5/Pump-: J1.8; also elsewhere on the board
/Pump Control6/Pump-: J1.6; also elsewhere on the board
/Pump Control7/Pump-: J1.4; also elsewhere on the board
/Pump Control8/Pump-: J1.2; also elsewhere on the board
GND: H1.1, H2.1, H3.1, H4.1, J2.2, J2.4, J3.1, J5.1; also elsewhere on the board
unnamed: F1.2, J2.1, J2.3
Pump1: J5.5; also elsewhere on the board
Pump2: J5.4; also elsewhere on the board
Pump3: J5.3; also elsewhere on the board
Pump4: J5.2; also elsewhere on the board
Pump5: J3.5; also elsewhere on the board
Pump6: J3.4; also elsewhere on the board
Pump7: J3.3; also elsewhere on the board
Pump8: J3.2; also elsewhere on the board

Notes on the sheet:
Pump Control
Raspberry Pi Connect
Power In / Out

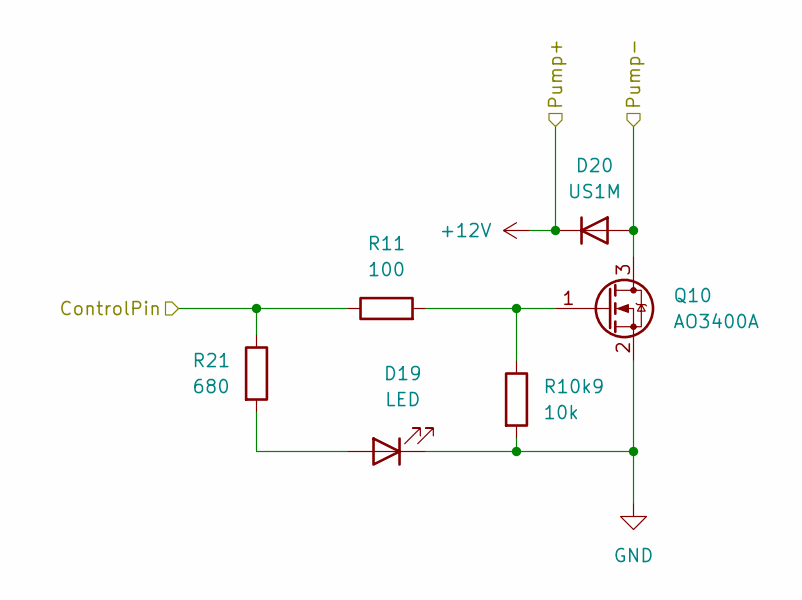
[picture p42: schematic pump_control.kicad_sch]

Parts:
D19: LED; LED_0603_1608Metric; mpn C2286
D20: US1M; D_SMA; mpn C412437
Q10: AO3400A; SOT-23; mpn C20917
R10k9: 10k; R_0603_1608Metric; mpn C25804
R11: 100; R_0603_1608Metric; mpn C22775
R21: 680; R_0603_1608Metric; mpn C23228

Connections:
+12V: D20.1 (K); also elsewhere on the board
/Pump Control1/Pump-: D20.2 (A), Q10.3 (D); also elsewhere on the board
GND: D19.1 (K), Q10.2 (S), R10k9.2; also elsewhere on the board
unnamed: D19.2 (A), R21.2
unnamed: Q10.1 (G), R10k9.1, R11.2
Pump1: R11.1, R21.1; also elsewhere on the board

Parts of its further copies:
D1, D3, D5, D11, D13, D15, D17: LED; LED_0603_1608Metric; mpn C2286
D2, D4, D6, D12, D14, D16, D18: US1M; D_SMA; mpn C412437
Q1, Q2, Q3, Q6, Q7, Q8, Q9: AO3400A; SOT-23; mpn C20917
R1, R3, R4, R7, R8, R9, R10: 100; R_0603_1608Metric; mpn C22775
R2, R10k1, R10k2, R10k5, R10k6, R10k7, R10k8: 10k; R_0603_1608Metric; mpn C25804

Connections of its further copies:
+12V: D2.1 (K), D4.1 (K), D6.1 (K), D12.1 (K), D14.1 (K), D16.1 (K), D18.1 (K); also elsewhere on the board
/Pump Control2/Pump-: D18.2 (A), Q9.3 (D); also elsewhere on the board
/Pump Control3/Pump-: D16.2 (A), Q8.3 (D); also elsewhere on the board
/Pump Control4/Pump-: D14.2 (A), Q7.3 (D); also elsewhere on the board
/Pump Control5/Pump-: D12.2 (A), Q6.3 (D); also elsewhere on the board
/Pump Control6/Pump-: D2.2 (A), Q1.3 (D); also elsewhere on the board
/Pump Control7/Pump-: D4.2 (A), Q2.3 (D); also elsewhere on the board
/Pump Control8/Pump-: D6.2 (A), Q3.3 (D); also elsewhere on the board
GND: D1.1 (K), D3.1 (K), D5.1 (K), D11.1 (K), D13.1 (K), D15.1 (K), D17.1 (K), Q1.2 (S), Q2.2 (S), Q3.2 (S), Q6.2 (S), Q7.2 (S), Q8.2 (S), Q9.2 (S), R2.2, R10k1.2, R10k2.2, R10k5.2, R10k6.2, R10k7.2, R10k8.2; also elsewhere on the board
unnamed 10: D1.2 (A); also elsewhere on the board
unnamed 11: D3.2 (A); also elsewhere on the board
unnamed 12: D5.2 (A); also elsewhere on the board
unnamed 13: D11.2 (A); also elsewhere on the board
unnamed 14: D13.2 (A); also elsewhere on the board
unnamed 15: D15.2 (A); also elsewhere on the board
unnamed 16: D17.2 (A); also elsewhere on the board
unnamed: Q1.1 (G), R1.2, R2.1
unnamed: Q2.1 (G), R3.2, R10k1.1
unnamed: Q3.1 (G), R4.2, R10k2.1
unnamed: Q6.1 (G), R7.2, R10k5.1
unnamed: Q7.1 (G), R8.2, R10k6.1
unnamed: Q8.1 (G), R9.2, R10k7.1
unnamed: Q9.1 (G), R10.2, R10k8.1
Pump2: R10.1; also elsewhere on the board
Pump3: R9.1; also elsewhere on the board
Pump4: R8.1; also elsewhere on the board
Pump5: R7.1; also elsewhere on the board
Pump6: R1.1; also elsewhere on the board
Pump7: R3.1; also elsewhere on the board
Pump8: R4.1; also elsewhere on the board

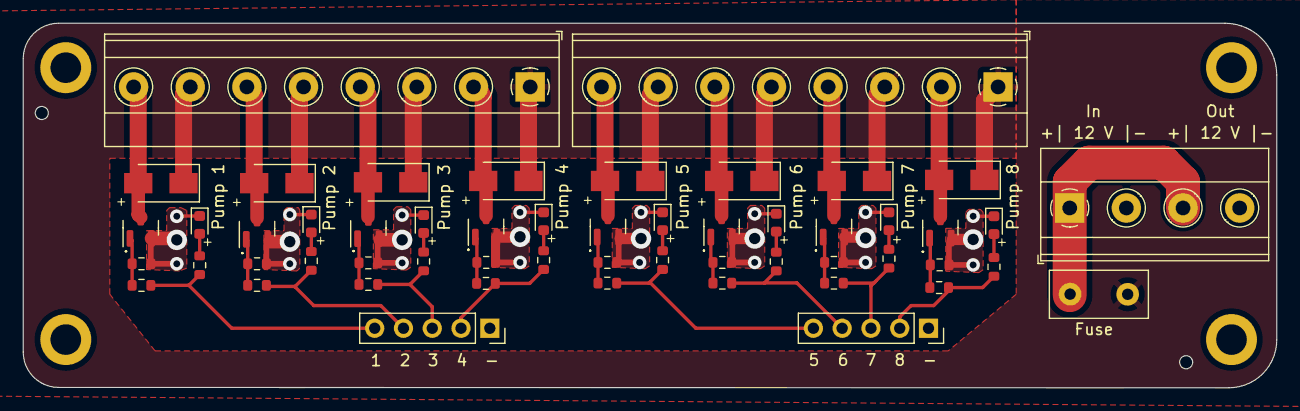
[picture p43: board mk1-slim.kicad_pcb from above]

Board: 2 copper layers, 110.6 x 32.2 mm, 58 parts (0 on the bottom side), 35 nets.

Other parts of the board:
R12, R13, R14, R17, R18, R19, R20: 220; R_0603_1608Metric

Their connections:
unnamed 10: R12.2; also elsewhere on the board
unnamed 11: R13.2; also elsewhere on the board
unnamed 12: R14.2; also elsewhere on the board
unnamed 13: R17.2; also elsewhere on the board
unnamed 14: R18.2; also elsewhere on the board
unnamed 15: R19.2; also elsewhere on the board
unnamed 16: R20.2; also elsewhere on the board
Pump2: R20.1; also elsewhere on the board
Pump3: R19.1; also elsewhere on the board
Pump4: R18.1; also elsewhere on the board
Pump5: R17.1; also elsewhere on the board
Pump6: R12.1; also elsewhere on the board
Pump7: R13.1; also elsewhere on the board
Pump8: R14.1; also elsewhere on the board

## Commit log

2026-06-16 first bodies test
    [DrainingRack.FCStd, DripTray.FCStd]
2026-06-17 fix part naming
    [DripTray.FCStd]
2026-06-17 add cad parameters
    [Parameters.FCStd]
2026-06-17 add cocktailberry board gpio
    [mk1-cbb.kicad_pcb, mk1-cbb.kicad_sch, pump_control.kicad_sch]
2026-06-17 add correction file
    [corrections.csv]
2026-06-21 base docs and files for mk3
    [Bundler.FCStd, DrainingRack.FCStd, DripTray.FCStd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]
2026-06-25 Finalize mk3
    [Bundler.FCStd, DrainingRack.FCStd, DripTray.FCStd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]
2026-06-25 add screws to mk3
    [TowerBottom.FCStd]
2026-06-25 adjust pcb git
2026-06-26 add 2-go parts
    [ElectricLid.FCStd, FootPlugs.FCStd, FootTransport.FCStd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]
2026-06-27 add docs for available pcbas
2026-06-27 add slim CBB
    [mk1-cbb.kicad_pcb, mk1-slim.kicad_pcb, mk1-slim.kicad_sch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]
2026-06-29 add first assembly image to mk4
2026-07-01 add cbb i2c base implementation
    [cbb-i2c.kicad_pcb, cbb-i2c.kicad_sch, corrections.csv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]
2026-07-01 adjust mcp routing
    [cbb-i2c.kicad_pcb, cbb-i2c.kicad_sch]
2026-07-01 use 0402 instead 0603 for mcp r
    [cbb-i2c.kicad_sch]
2026-07-01 adjust mpn property spelling
    [mk1-slim.kicad_sch]
2026-07-01 adjust corrections
    [corrections.csv]
2026-07-05 adjust cbb-i2c
    [cbb-i2c.kicad_pcb, cbb-i2c.kicad_sch]
2026-07-12 add mk4 freecad files
    [BasePlate.FCStd, Bottle.FCStd, Bundler.FCStd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]
2026-07-13 fix cbb slim power supply orientation in pos
    [corrections.csv]
2026-07-13 add info for cbb i2c
2026-07-15 add power indicator led to cbb i2c
    [cbb-i2c.kicad_pcb, cbb-i2c.kicad_sch]
2026-07-21 add accessory files
    [CocktailBerryPagePlates.3mf, PlateBox.3mf, PlateBox.FCStd]
2026-07-21 add cocktailberry plate to accessories
2026-07-21 adjust box
    [PlateBox.FCStd]
2026-07-21 Adjust box 3mf
    [PlateBox.3mf]
2026-07-21 adjust drip tray for scale/no scale
    [DrainingRackWithScale.FCStd, DripTray.FCStd, DripTrayWithScale.FCStd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]
2026-07-30 Add power cable clip to mk4
    [PowerCableClip.FCStd]
2026-08-01 make funnel outlet smaller for better flow
    [Funnel.FCStd]
2026-08-11 make tablet rest wider
    [Parameters.FCStd]
2026-08-22 adjust bundler and led plug sizing
    [Bundler.FCStd, LedHolePlug.FCStd]
2026-09-13 reduce brightness of channel indicator led
    [cbb-i2c.kicad_pcb, pump_control.kicad_sch]
2026-09-13 Adjust board version numbering
    [mk1-cbb.kicad_pcb, mk1-slim.kicad_pcb]
2026-10-10 Document NAU7802 scale wiring for MK IV
    Describe how to connect the NAU7802 scale board in the optional scale
    wiring section, both directly to the Raspberry Pi I2C pins (GPIO board)
    and to the pass-through I2C connectors of the CocktailBerry Board I2C.
    Add a 3.3 V warning and the software steps to enable and verify I2C.
2026-10-10 Document LED wiring for MK IV
    Describe how to connect the WS281x LED strip in the optional LED wiring
    section: data on GPIO 10 (SPI), and power either from the Raspberry Pi
    5 V pins for small loads or from the step-down converter output for
    larger LED counts. Add a current estimate, a converter rating warning,
    and the software settings.
2026-10-11 Use GPIO 18 for MK IV LEDs, add Pi 5 notes and LED test script
    - Use GPIO 18 (physical pin 12) as the LED data pin consistently
    - Add Raspberry Pi 5 instructions (GPIO 10 over SPI)
    - Note that onboard audio must be disabled for GPIO 18
    - Document testing the LEDs without CocktailBerry using
    scripts/led_test.py from the CocktailBerry software repo
    Claude-Session: https://claude.ai/code/session_011t6wiWUT87o9ciVYzfVZR6
2026-10-11 Use GPIO 10 (SPI) only for MK IV LEDs and run LED test with uv
    - LED data wire always on GPIO 10 (SPI MOSI, physical pin 19), works on
    every Raspberry Pi including the Pi 5; drop GPIO 18 / audio notes
    - Run scripts/led_test.py with uv from the CocktailBerry folder so the
    exact machine setup is used (requested in review)
    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
2026-10-11 Document LED test brightness in percent and typer options
    The LED test script now takes the brightness in percent (0-100, default 20),
    matching brightness in LED_CONFIG, and uses typer (short options -c/-b, --help).
    Claude-Session: https://claude.ai/code/session_01PDTfNPE8UHvSsRwuKJNg9Z
2026-10-11 Add LED troubleshooting to MK IV assembly guide
    Covers the missing SPI device, dark LEDs in CocktailBerry, and the Raspberry Pi 4
    strip turning white when the core clock drops (fixed via core_freq/core_freq_min).
    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
